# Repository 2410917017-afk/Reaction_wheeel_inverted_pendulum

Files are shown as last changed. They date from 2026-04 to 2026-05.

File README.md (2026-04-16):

# Reaction Wheel Inverted Pendulum 

> Plataforma educativa open-source de control moderno basada en un péndulo invertido con rueda de inercia. Implementa control LQR (Regulador Cuadrático Lineal) con modelado por mecánica Lagrangiana, simulación en MATLAB y hardware basado en ESP32.

<p align="center">
  Ensamble CAD
</p>

<p align="center">
  
  
  
  
  
</p>

---

##  Descripción del proyecto

El **Reaction Wheel Inverted Pendulum (RWIP)** es un sistema mecatrónico que mantiene un péndulo en posición vertical utilizando el momento angular generado por una rueda giratoria montada en su extremo superior. A diferencia del péndulo de carro clásico, no requiere traslación lineal — el único actuador es el motor que acelera y desacelera la rueda de inercia.

Este proyecto implementa:

- **Modelado matemático completo** mediante mecánica Lagrangiana
- **Linealización** del sistema no lineal alrededor del punto de equilibrio inestable
- **Representación en espacio de estados** con verificación de controlabilidad
- **Diseño del controlador LQR** mediante la ecuación algebraica de Riccati
- **Simulación no lineal** en MATLAB/Simulink con comparación lineal vs no lineal
- **Sensado** con encoder incremental óptico (ángulo péndulo) y encoder magnético AS5600 (velocidad rueda)
- **Estructura mecánica** completamente imprimible en 3D

---

##  Motivación y problemática

Los estudiantes de ingeniería en control moderno aprenden conceptos como espacio de estados y LQR sin acceso a plantas físicas para experimentar. Las plataformas comerciales equivalentes como el **Quanser QUBE-Servo 2** tienen un costo de entre **\$3,000 y \$8,000 USD**, lo que las hace inaccesibles para la mayoría de instituciones educativas en México y Latinoamérica.

Este proyecto propone una plataforma educativa **open-source y replicable** con un costo de aproximadamente **\$30–45 USD**, que permite:

- Derivar y verificar experimentalmente el modelo matemático de un sistema no lineal real
- Implementar y comparar estrategias de control (PID vs LQR)
- Visualizar en tiempo real el efecto de cada ganancia del controlador
- Replicarse en cualquier institución con impresora 3D

El principio físico de las reaction wheels es el mismo utilizado en **satélites y telescopios espaciales** para control de actitud sin propulsión química, lo que le da al proyecto un contexto de aplicación de alto impacto.

---

##  Teoría y fundamentos

### Sistema físico

El sistema tiene **2 grados de libertad**:
- `θ` — ángulo del péndulo respecto a la vertical
- `φ` — ángulo de la rueda respecto al péndulo

### Ecuaciones de movimiento (Lagrangiano)

La energía cinética total del sistema es:

$$T = \frac{1}{2}(I_p + m_w L^2)\dot{\theta}^2 + \frac{1}{2}I_w(\dot{\theta} + \dot{\phi})^2$$

Donde el primer término incluye la contribución traslacional de la rueda mediante el teorema de Steiner. Aplicando las ecuaciones de Euler-Lagrange se obtiene:

$$\ddot{\theta} = \frac{(m_p l + m_w L)g\sin\theta - \tau}{I_{total}}$$

$$\ddot{\phi} = \frac{\tau}{I_w} - \ddot{\theta}$$

### Linealización y espacio de estados

Linealizando alrededor de `θ = 0` con `sin θ ≈ θ`, el sistema toma la forma:

$$\dot{\mathbf{x}} = A\mathbf{x} + Bu, \quad \mathbf{x} = \begin{bmatrix}\theta \\ \dot{\theta} \\ \dot{\phi}\end{bmatrix}$$

$$A = \begin{bmatrix} 0 & 1 & 0 \\ \frac{M_g}{I_{total}} & 0 & 0 \\ -\frac{M_g}{I_{total}} & 0 & -\frac{b_{eq}}{I_w} \end{bmatrix}, \quad B = \begin{bmatrix} 0 \\ -\frac{1}{I_{total}} \\ \frac{1}{I_w} + \frac{1}{I_{total}} \end{bmatrix}$$

### Control LQR

El controlador LQR minimiza la función de costo:

$$J = \int_0^\infty (\mathbf{x}^T Q \mathbf{x} + u^T R u)\, dt$$

Las ganancias óptimas `K` se obtienen resolviendo la Ecuación Algebraica de Riccati:

$$A^T P + PA - PBR^{-1}B^T P + Q = 0 \quad \Rightarrow \quad K = R^{-1}B^T P$$

La ley de control es `u = -Kx`, con `u` siendo el voltaje aplicado al motor.

Para la derivación completa con todos los pasos intermedios, ver [`docs/teoria_completa.pdf`](docs/teoria_completa.pdf).

---

##  Estructura del repositorio

```
Reaction_wheel_pendulum/
│
│
├── CAD/                             # Diseño mecánico
│   ├── STL/                         # Archivos listos para imprimir
│   │   ├── Arm_V10_STL.stl
│   │   ├── Support_V5.stl
│   │   ├── Tower_V7_STL.stl
│   │   └── Wheel_V5_STL.stl
│   ├──planos/                      # Planos dimensionales PDF
│   │   ├── Arm.pdf
│   │   ├── ExplodedView.pdf
│   │   ├── Support_V5.pdf
│   │   ├── Tower_V7.pdf
│   │   └── Wheel_V5_Sheet.pdf
│   └──step/                        # Archivos STEP 
│       └── ensamble_completo.step
│
├── System_dinamics_test/            # Simulación y diseño de control
│   ├── params.m                     # Parámetros físicos del sistema
│   ├── model.m                      # Matrices A,B, controlabilidad, LQR
│   ├── simulation.m                 # Simulación no lineal ODE45
│   ├── system.m                     # Función dinámica no lineal 
│   └── resultados/                  # Gráficas exportadas
│       ├── respuesta_lineal.png
│       ├── simulacion_no_lineal.png
│       ├── lineal_vs_nolineal.png
│       └── lugar_de_raices.png
│
├── docs/                            # Documentación adicional
│   ├── teoria_completa.pdf          # Derivación matemática completa
│   └── img/
│       └── Assembly 1.png
│
├── src/                        # Código ESP32
│   ├── main/
│   │   ├── rwp_main.ino             # Controlador LQR completo
│   │   └── real_time_monitor.py     # Monitor en tiempo real
│   └── tools/
│       ├── sensors.h                # Lectura AS5600 + Encoder
│       └── identify_deadzone.ino    # Identificación zona muerta motor
│
├── electronics/                     # Diseño electrónico
│   └── schematic.pdf                # Esquemático completo
│
├── README.md
└── LICENSE

```

---

##  Hardware requerido

### Lista de componentes

| Componente | Modelo | Cantidad | Función | Costo aprox. |
|---|---|---|---|---|
| Microcontrolador | ESP32 DevKit v1 | 1 | Control en tiempo real | \$5–8 USD |
| Encoder ángulo péndulo | 3806-OPTI-600-AB-OC | 1 | Medir θ | (disponible) |
| Encoder velocidad rueda | AS5600 + imán diametral | 1 | Medir φ̇ | \$3–4 USD |
| Motor reaction wheel | Motor DC 775 sin reductora | 1 | Actuador | \$5–8 USD |
| Driver de motor | L298N o TB6612FNG | 1 | Amplificar señal PWM | \$2–4 USD |
| Fuente de poder | LiPo 18V o fuente regulada | 1 | Alimentación motor | \$8–12 USD |
| Rodamientos | 608-2RS (8mm) | 2 | Pivote del péndulo | \$1–2 USD |
| Tornillería | M3 × 10mm, M3 × 20mm | surtido | Ensamble | \$1 USD |
| Filamento 3D | PLA o PETG | ~250g | Estructura | \$3–5 USD |

**Costo total estimado: \$28–44 USD**

### Parámetros físicos del sistema (CAD)

| Parámetro | Símbolo | Valor | Fuente |
|---|---|---|---|
| Masa brazo + motor | `m_p` | 0.42 kg | Onshape |
| Distancia pivote-CM péndulo | `l` | 0.18 m | Onshape |
| Distancia pivote-rueda | `L` | 0.20 m | Onshape |
| Inercia total respecto al pivote | `I_total` | 0.0212 kg·m² | Onshape |
| Masa de la rueda | `m_w` | 0.09 kg | Onshape |
| Radio de la rueda | `r_w` | 0.06 m | CAD |
| Inercia de la rueda | `I_w` | 3.24×10⁻⁴ kg·m² | Calculado |

### Parámetros del motor 775

| Parámetro | Símbolo | Valor | Fuente |
|---|---|---|---|
| Resistencia de armadura | `Ra` | 0.80 Ω | Datasheet / medición |
| Constante de torque | `Kt` | 0.038 N·m/A | Datasheet / medición |
| Constante FCEM | `Ke` | 0.038 V·s/rad | Datasheet / medición |
| Voltaje nominal | `Vmax` | 18 V | — |
| Torque máximo | `τ_max` | 0.855 N·m | Calculado |

---

Notas:
  • Encoder 3806: pull-up 3.3kΩ en canal A y B hacia 3.3V (open collector)
  • AS5600: imán diametral centrado a 0.5–3mm del sensor
  • Capacitor 100µF entre VCC y GND del driver (desacoplo)
  • Masa común entre ESP32, driver y fuente

El esquemático completo en EasyEDA se encuentra en [`electronics/schematic.pdf`](electronics/schematic.pdf).

---

##  Instalación y uso

### Requisitos

- Arduino IDE 2.x con soporte ESP32 (board manager: `https://dl.espressif.com/dl/package_esp32_index.json`)
- Librería `Wire.h` (incluida en ESP32 core)
- MATLAB R2022a o superior (para simulación)
- Python 3.8+ con `pyserial` y `matplotlib` (para telemetría en tiempo real)

### 1. Clonar el repositorio

```bash
git clone https://github.com/tu-usuario/reaction-wheel-pendulum.git
cd reaction-wheel-pendulum
``` 

### 2. Configurar parámetros

Edita `firmware/main/config.h` con tus ganancias de MATLAB:

```cpp
// Ganancias LQR — copiar exactamente de MATLAB
const float K_theta    = 15.0;
const float K_thetadot = 8.0;
const float K_phidot   = 2.0;

// Parámetros del sistema
const float VMAX          = 18.0;
const float THETA_MAX_DEG = 25.0;
const int   PWM_DEADZONE  = 18;
```

### 3. Cargar firmware al ESP32

```bash
# Desde Arduino IDE: seleccionar placa "ESP32 Dev Module"
# Puerto: el que corresponda a tu ESP32
# Cargar rwp_main.ino
```

### 4. Flujo de operación

```
1. Encender → verificar salida serial (115200 baud)
2. Confirmar "✓ Imán OK" del AS5600
3. Posicionar péndulo en vertical
4. Enviar cualquier carácter por serial → establece cero
5. Enviar 'S' → activa el controlador
6. Enviar 'P' → pausa
7. Enviar 'R' → restablece cero si el péndulo cayó
```

### 5. Visualización en tiempo real (opcional)

```bash
pip install pyserial matplotlib
python docs/graficar_serial.py
# Editar PORT en el script según tu sistema
```

---

##  Simulación en MATLAB

### Correr la simulación completa

```matlab
% En MATLAB, desde la carpeta /matlab:
run('Parametros.m')   % 1. Cargar parámetros físicos
run('Modelo.m')       % 2. Diseñar LQR y verificar estabilidad
run('Simulacion.m')   % 3. Simular sistema no lineal
```

### Parámetros de diseño LQR

```matlab
% Matrices de peso — ajustables
Q = diag([10, 8, 5]);   % [q_theta, q_thetadot, q_phidot]
R = 300;                % penalización del esfuerzo de control
```

### Resultados de simulación

| Métrica | Valor |
|---|---|
| Condición inicial | 8.59° |
| Tiempo de establecimiento | 0.140 s |
| Sobreimpulso | 0.0 % |
| Control máximo | 4.59 V |
| Margen de voltaje | 74.5% |
| Polos en lazo cerrado | parte real negativa ✓ |

---

##  Resultados

### Respuesta del controlador LQR

<p align="center">
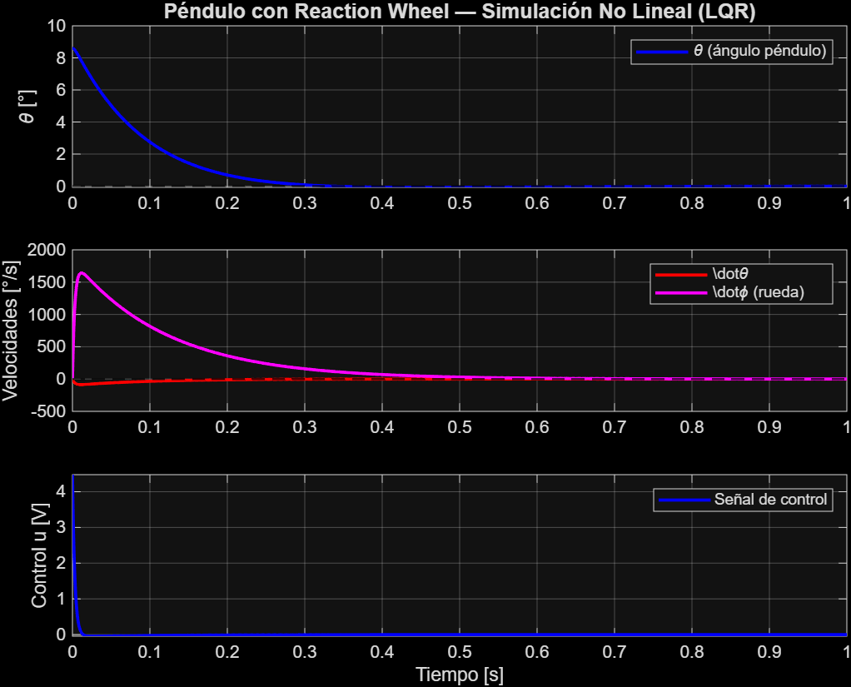
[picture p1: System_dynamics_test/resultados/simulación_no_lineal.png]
  
</p>

### Comparación modelo lineal vs no lineal

<p align="center">
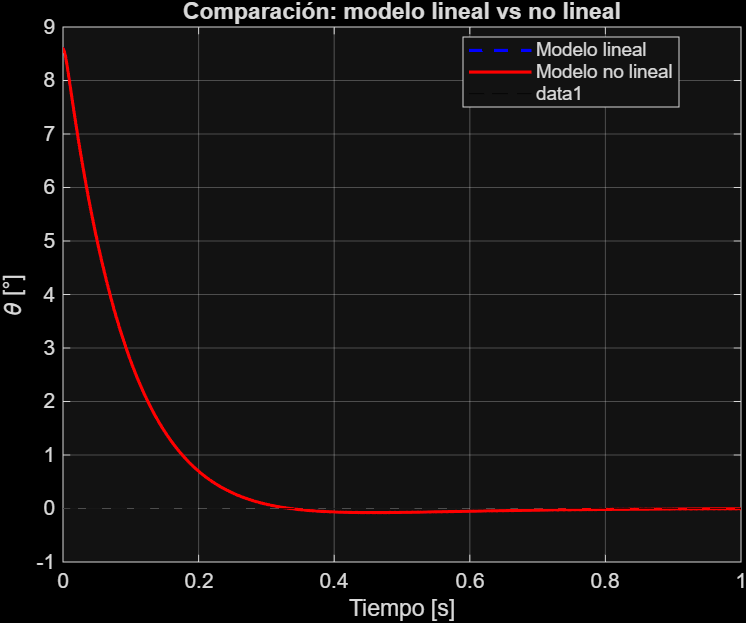
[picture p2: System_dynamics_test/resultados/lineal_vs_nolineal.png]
  
</p>

La diferencia entre ambos modelos corresponde al error de linealización (`sinθ ≈ θ`), que produce un undershoot de ~0.8° en el modelo no lineal. Este comportamiento es esperado y se documenta como parte del análisis de validez del modelo linealizado.

---

##  Trabajo futuro

- [ ] **Identificación experimental** de parámetros del motor (Kt, Ra, Ke)
- [ ] **Comparación PID vs LQR** con métricas cuantitativas (ISE, IAE, ITAE)
- [ ] **Control swing-up** mediante control por energía para llevar el péndulo desde posición colgante hasta vertical
- [ ] **Filtro de Kalman** para estimación de estados con fusión de sensores
- [ ] **Extensión a 2 ejes** (dual axis reaction wheel — balanceo sobre una punta)
- [ ] **Interfaz web** vía WiFi del ESP32 para ajuste de ganancias en tiempo real
- [ ] **Validación experimental** con comparación cuantitativa simulación vs hardware

---

##  Referencias

1. Krafes, S. et al. *"Design, Implementation, and Control of a Wheel-Based Inverted Pendulum"*, MDPI Electronics, 2024. [DOI: 10.3390/electronics13030514](https://doi.org/10.3390/electronics13030514)

2. Nguyen, B.H. et al. *"Modelling and control of a reaction wheel pendulum using a linear quadratic regulator"*, ResearchGate, 2021. [Link](https://www.researchgate.net/publication/351314795)

3. Gajamohan, M. et al. *"Nonlinear Analysis and Control of a Reaction Wheel-based 3D Inverted Pendulum (Cubli)"*, ETH Zürich, 2013. [PDF](https://ethz.ch/content/dam/ethz/special-interest/mavt/dynamic-systems-n-control/idsc-dam/Research_DAndrea/Cubli/RevisedManuscript.pdf)

4. Borase, R.P. et al. *"Reaction Wheel Pendulum Stabilization Using Various State-Space Representations"*, MDPI Electronics, 2025. [DOI: 10.3390/electronics14234719](https://doi.org/10.3390/electronics14234719)

5. SimpleFOC Project. *"Arduino BLDC Reaction Wheel Inverted Pendulum"*. [GitHub](https://github.com/simplefoc/Arduino-FOC-reaction-wheel-inverted-pendulum)

6. Rouleau, M. *"Self-Balancing Stick — Dual Axis Reaction Wheel Inverted Pendulum"*. [GrabCAD](https://grabcad.com/library/self-balancing-stick-dual-axis-reaction-wheel-inverted-pendulum-1)

---

##  Autor

Desarrollado como **proyecto integrador de 5° cuatrimestre** de la carrera de Ingeniería Mecatrónica **Institución:** Universidad Tecnológica de Corregidora
**Materia:** Sistemas de Control / Proyecto Integrador  
**Periodo:** 2026

---

##  Licencia

Este proyecto está bajo la licencia MIT. Consulta el archivo [LICENSE](LICENSE) para más detalles.

Puedes usar, modificar y distribuir este proyecto libremente, incluyendo para fines educativos e institucionales. Si lo usas en un trabajo académico, se agradece la cita correspondiente.

---

<p align="center">
  Hecho con café y demasiadas horas en MATLAB
</p>

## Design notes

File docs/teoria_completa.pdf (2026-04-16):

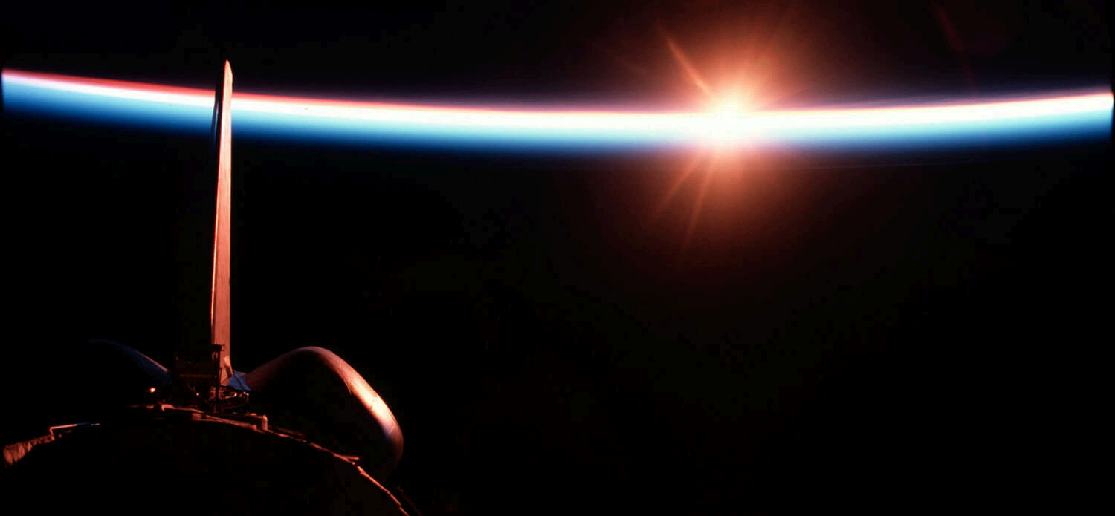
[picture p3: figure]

# Teoría sobre: Péndulo invertido con rueda de reacción

## Definición del sistema

Primero establece claramente qué es el sistema físicamente antes de escribir una sola ecuación.

### Variables y parámetros

Parámetros físicos:
m_p = masa del cuerpo del péndulo (brazo + motor) m_w = masa de la reaction wheel
l | = distancia del pivote al CM del péndulo
L | = longitud total del brazo
I_p = momento de inercia del péndulo respecto al pivote I_w = momento de inercia de la rueda respecto a su centro
g | = 9.81 m/s²
τ | = torque del motor (entrada de control)

Coordenadas generalizadas:
θ | = ángulo del péndulo respecto a la vertical (= 0 arriba)
φ | = ángulo de la rueda respecto al péndulo

El sistema tiene 2 grados de libertad, 2 coordenadas generalizadas y terminan en 2 ecuaciones de movimiento.

## Parte 2 — Formalismo de Euler-Lagrange

Con Newton necesitas calcular fuerzas de reacción internas. Con Lagrange trabajas directamente con energías, que son escalares y mucho más fáciles de manejar. La

Teoría sobre: Péndulo invertido con rueda de reacción | 1

ecuación fundamental es:

Donde:

L = T - V es el Lagrangiano

q_i son las coordenadas generalizadas

Q_i son las fuerzas o torques externos

## Parte 3 — Energía cinética

El sistema tiene dos cuerpos en movimiento: el péndulo y la rueda.

### Energía cinética del péndulo

El péndulo rota alrededor del pivote fijo con velocidad angular θ̇ :

### Energía cinética de la rueda

La rueda tiene dos movimientos simultáneos:

Rota con el péndulo a velocidad θ̇

Rota respecto al péndulo a velocidad φ̇

Su velocidad angular absoluta es la suma:

### Energía cinética total

Expandiendo el cuadrado:

## Parte 4 — Energía potencial

Solo la gravedad contribuye. Tomando como referencia el nivel del pivote, el CM del péndulo sube o baja según θ :

−
dt

d (
∂q˙i

∂L ) =
∂qi

∂L Qi

Tp = I
2

1
pθ

˙2

## Tw = I ( +

2

1
w θ

˙ ϕ)

˙ 2

T = Tp + Tw = I +
2

1
pθ

˙2 I ( +
2

1
w θ

˙ ϕ)

˙ 2

## T = (I + I ) + I + I

2

1
p | w θ
˙2 | wθ

˙ϕ˙
2

1
wϕ˙2

La rueda está al final del brazo a distancia L , y su CM coincide con el eje del motor. Simplificando con M = m_p referido al CM y agrupando:

Una convención común al formular esta ecuación es tomarlo como positivo, esto debido el eje cartesiano con el que se referencia el ángulo θ :

## Parte 5 — El Lagrangiano

## Parte 6 — Aplicar Euler-Lagrange

### Para θ

Paso 1 — Derivada parcial respecto a θ̇ :

Paso 2 — Derivada total respecto al tiempo:

Paso 3 — Derivada parcial respecto a θ :

Paso 4 — Ensamblar. El torque externo en θ es cero

V = −mpgl cos θ − mwgLcos θ

## V = −(mpl + mwL)g cos θ

V = (mpl + mwL)g cos θ

L = T − V

L = (I + I ) + I | + I | − (m l + m L)g cos θ
2

1
p | w θ
˙2 | wθ

˙ϕ˙
2

1
wϕ˙2
p | w

=
∂θ

˙

∂L

## (Ip + Iw)θ

## ˙ + Iwϕ˙

=
dt

d
∂θ

˙

∂L

## (Ip + Iw)θ¨+ Iwϕ¨

=
∂θ

∂L

## (mpl + mwL)g sin θ

Qθ = 0

−
dt

d
∂θ

˙

∂L =
∂θ

∂L
0

### Para φ

Paso 1 — Derivada parcial respecto a φ̇ :

Paso 2 — Derivada total respecto al tiempo:

Paso 3 — Derivada parcial respecto a φ :

Paso 4 — El torque externo en φ es el torque del motor τ :

## Parte 7 — Despejar las aceleraciones

De la ecuación (2):

Sustituyendo (2') en (1):

(Ip + Iw)θ + I | − (m l + m L)g sin θ = 0
¨ | wϕ¨
p | w | (1)

=
∂ϕ˙

∂L
Iwθ

## ˙ + Iwϕ˙ = Iw(θ

˙ + ϕ)

˙

=
dt

d
∂ϕ˙

∂L

## Iw(θ¨+ ϕ)¨

=
∂ϕ

∂L
0

Qϕ = τ

−
dt

d
∂ϕ˙

∂L =
∂ϕ

∂L
τ
Iw(θ + ) = τ ¨ ϕ¨ | (2)
ϕ¨ = | −
Iw

τ
θ¨ | (2’)
(Ip + Iw)θ¨+ Iw ( − | =
Iw τ | θ¨) (mpl + mwL)g sin θ

## (Ip + Iw)θ¨+ τ − Iwθ¨ = (mpl + mwL)g sin θ

Ipθ¨ = (mpl + mwL)g sin θ − τ

Y sustituyendo (3) en (2'):

Estas son las ecuaciones de movimiento no lineales del sistema. El sinθ es la no linealidad.

## Parte 8 — Linealización

El sistema opera cerca de θ = 0 (posición vertical). Para θ pequeño:

Definiendo por simplicidad:

Las ecuaciones linealizadas quedan:

## Parte 9 — Espacio de Estados

En lugar de manejar ecuaciones diferenciales de segundo orden, se define un vector de variables llamadas estados y reescribes todo como un sistema de ecuaciones de primer orden:

Donde A , B , C , D son matrices constantes, u es la entrada y y la salida.

### Definición de estados

Elige los estados como las variables que describen completamente el sistema en cualquier instante:

θ¨ =
Ip

## (mpl + mwL)g sin θ − τ

(3)

ϕ¨ = −
Iw

τ
Ip

## (mpl + mwL)g sin θ − τ

(4)

## sin θ ≈ θ, cos θ ≈ 1

Mg = (mpl + mwL)g

θ¨ =
Ip

Mg ⋅ θ − τ
(5)

ϕ¨ = −
Iw

τ
Ip

Mg ⋅ θ − τ
(6)

x˙ = Ax + Buy = Cx + Du

x = [x1 x2 x3] = [θ θ

˙ ϕ˙]

La entrada es el torque del motor:

### Derivadas de los estados

### Forma matricial

Los valores propios de A te dicen si el sistema es estable en lazo abierto. Si alguno tiene parte real positiva → inestable → necesitas control. Spoiler: sí los tiene, por eso el péndulo se cae solo.

### Verificar controlabilidad

Antes de diseñar el controlador verifica que el sistema sea controlable — que el actuador pueda afectar todos los estados:

Si det(C) ≠ 0 el sistema es controlable y puedes proceder.

## Parte 10 — Control LQR

### La idea central

LQR busca una ley de control de la forma:

Es decir, retroalimenta todos los estados con ganancias K_1, K_2, K_3 .

### La función de costo

LQR elige las ganancias que minimizan este índice de desempeño:

u = τ

x˙ 1 = θ

˙ = x2

## x˙ 2 = θ¨ = x −

Ip

Mg

### 1 u

Ip

1

## x˙ 3 = ϕ¨ = − x +

Ip

Mg

1 | ( + | u
Iw

1
Ip

1 )

C = [B AB A²B]

u = −Kx = − [K1 | K2 | K3] [θ θ

˙ ϕ

˙]

J = ∫ x Qx + u Ru dt

0

∞
(
T | T | )

El primer término penaliza que los estados se alejen del origen (que el péndulo se incline). El segundo penaliza el esfuerzo de control (que el motor trabaje de más). Tú decides qué tan importante es cada cosa eligiendo las matrices Q y R .

### Las matrices Q y R

Q es una matriz diagonal de 3×3 (uno por estado) y R es un escalar para este sistema:

Interpretación práctica:

q_1 grande → priorizas que θ vuelva a cero rápido → controlador agresivo en ángulo

q_2 grande → priorizas que θ̇ sea pequeña → penalizas oscilaciones

q_3 grande → priorizas que la rueda no acelere indefinidamente

r grande → el motor se mueve suavemente pero reacciona más lento

El tradeoff fundamental: entre más agresivo el control, más rápido estabiliza pero más corriente consume y más se desgasta el motor.

### La ecuación de Riccati

La solución matemática de ese problema de optimización lleva a resolver la Ecuación Algebraica de Riccati (ARE):

Esta ecuación tiene como incógnita la matriz P (simétrica positiva definida). Una vez resuelta, las ganancias óptimas son:

En la práctica no resuelves esto a mano — lo hace MATLAB con una línea:

% Datos del sistema
A = [...]; B = [...];
Q = diag([q1, q2, q3]);
R = r;

% Resolver Riccati y obtener ganancias [K, P, eig_cl] = lqr(A, B, Q, R);

% Verificar polos en lazo cerrado disp(eig_cl)

O en Python:

Q = [q1 | 0 0 0 q2 | 0 0 0 q3] , R = r

A P +

T PA − PBR B P +

−1 T Q = 0

K = R B P

−1 T

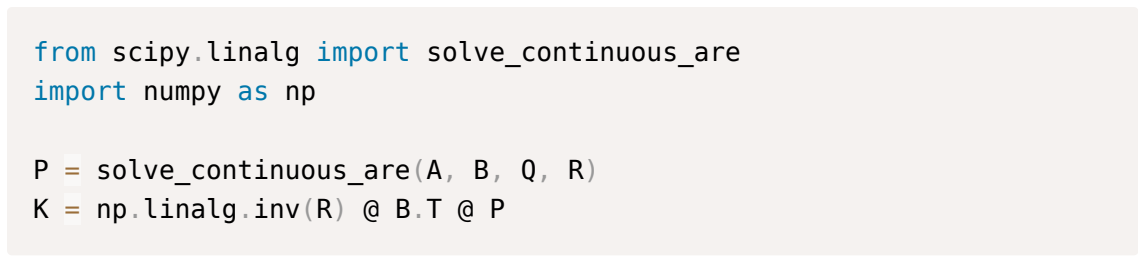
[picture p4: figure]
from scipy.linalg import solve_continuous_are import numpy as np; solve_continuous_are(A, B, Q, R); np.linalg.inv(R) @ B.T @ P

### Lazo cerrado

Sustituyendo u = -Kx en el sistema:

El sistema en lazo cerrado tiene matriz A_cl = A - BK . Los valores propios de esta matriz determinan la estabilidad — todos deben tener parte real negativa para que el péndulo se estabilice.

## Resumen del flujo completo

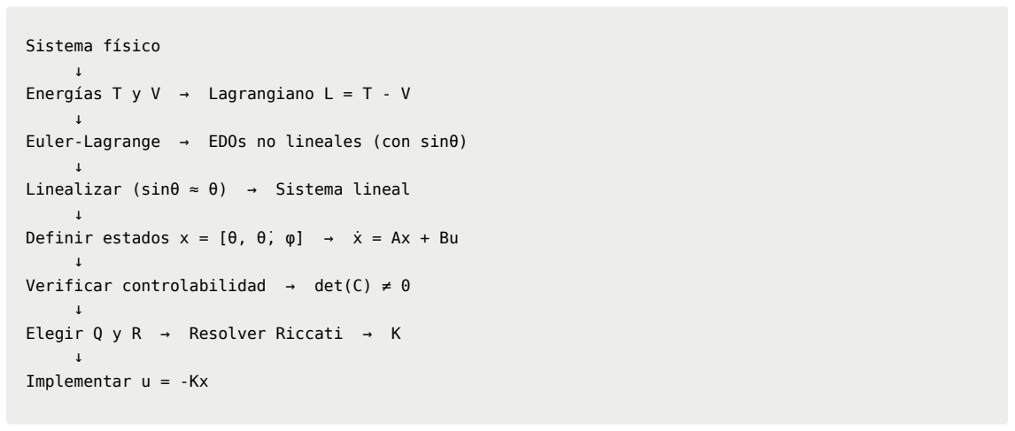
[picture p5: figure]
Sistema físico ↓ Energías T y V → Lagrangiano L = T - V ↓; ↓ Linealizar (sinθ ≈ θ) → Sistema lineal ↓; ↓ Verificar controlabilidad → det(C) ≠ 0 ↓ Elegir Q y R → Resolver Riccati → K ↓ Implementar u = -Kx

Euler-Lagrange → EDOs no lineales (con sinθ)

Definir estados x = [θ, θ̇, φ̇] → ẋ = Ax + Bu

## Referencias

1. Ogata, Katsuhiko. Ingeniería de control moderna. Quinta edición. México, D.F.: Prentice-Hall Hispanoamericana, 2017. (https://www.bing.com/ck/a?!&ptn=3&ver=2&hsh=4&fclid=2927917e-95d4-6cd1-2a0e-866794986d7e&ntb=1)
2. Krafes, S. et al. "Design, Implementation, and Control of a Wheel-Based Inverted Pendulum", MDPI Electronics, 2024. DOI: 10.3390/electronics13030514 (https://doi.org/10.3390/electronics13030514)
3. Nguyen, B.H. et al. "Modelling and control of a reaction wheel pendulum using a linear quadratic regulator", ResearchGate, 2021. Link (https://www.researchgate.net/publication/351314795)
4. Gajamohan, M. et al. "Nonlinear Analysis and Control of a Reaction Wheel-based 3D Inverted Pendulum (Cubli)", ETH Zürich, 2013. PDF (https://ethz.ch/content/dam/ethz/special-interest/mavt/dynamic-systems-n-control/idsc-dam/Research_DAndrea/Cubli/RevisedManuscript.pdf)

## x˙ = Ax + B(−Kx) = (A − BK)x

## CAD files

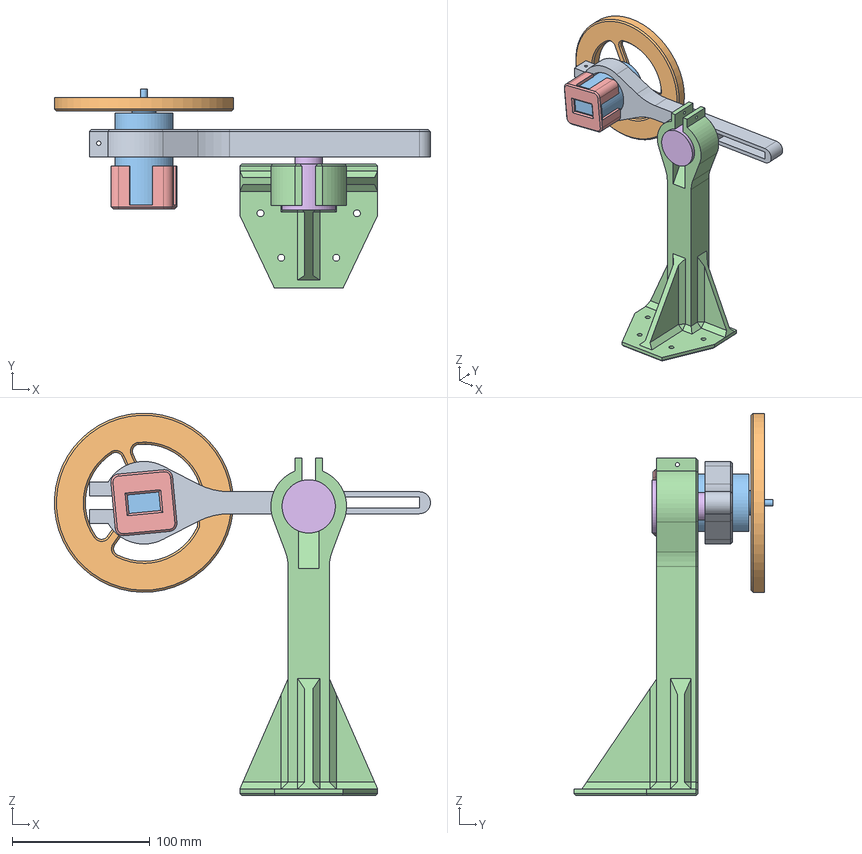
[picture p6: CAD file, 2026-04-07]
CAD/step/ensamble_completo.step
272.9 x 144.3 x 277.6 mm

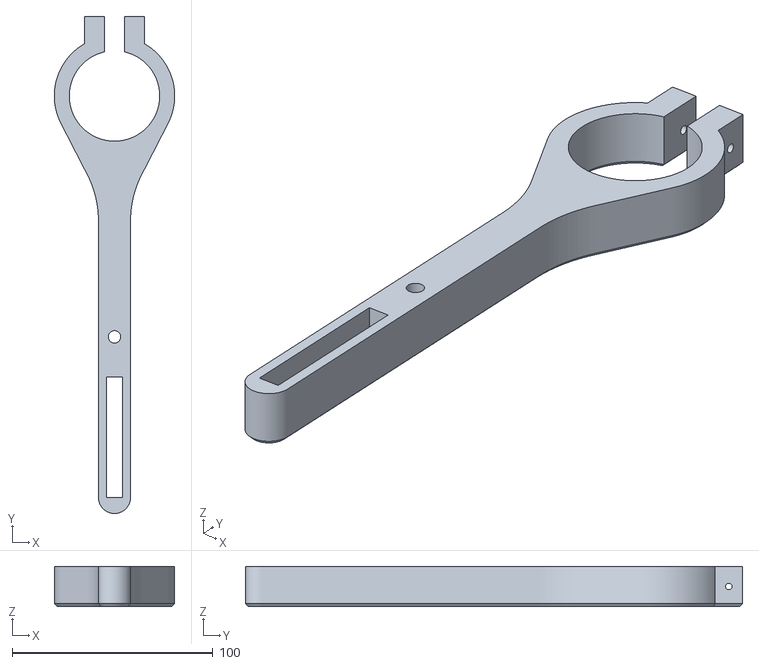
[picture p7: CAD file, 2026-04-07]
CAD/STL/Arm_V10_STL.stl
60.0 x 247.6 x 20.0

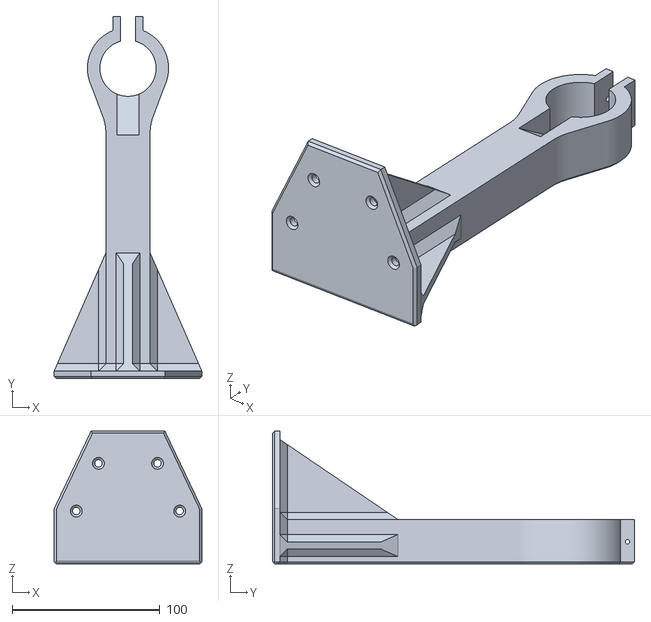
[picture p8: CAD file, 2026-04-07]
CAD/STL/Tower_V7_STL.stl
100.0 x 245.0 x 90.0

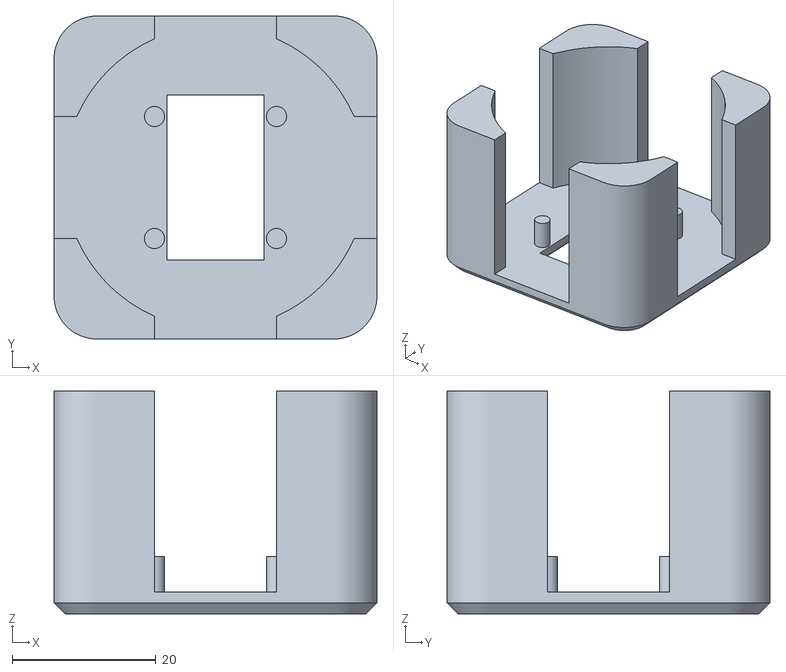
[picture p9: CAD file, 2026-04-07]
CAD/STL/Support_V5.stl
45.0 x 45.0 x 31.0

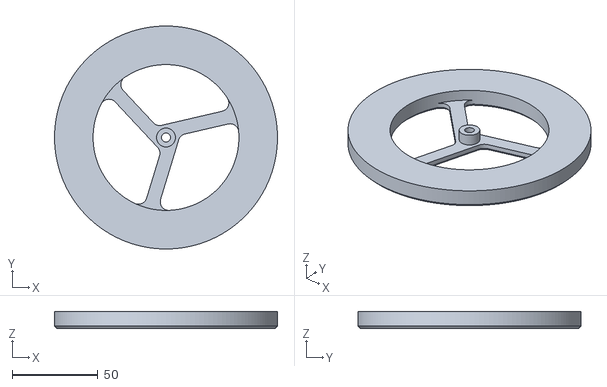
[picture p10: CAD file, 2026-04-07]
CAD/STL/Wheel_V5_STL.stl
130.0 x 130.0 x 10.0

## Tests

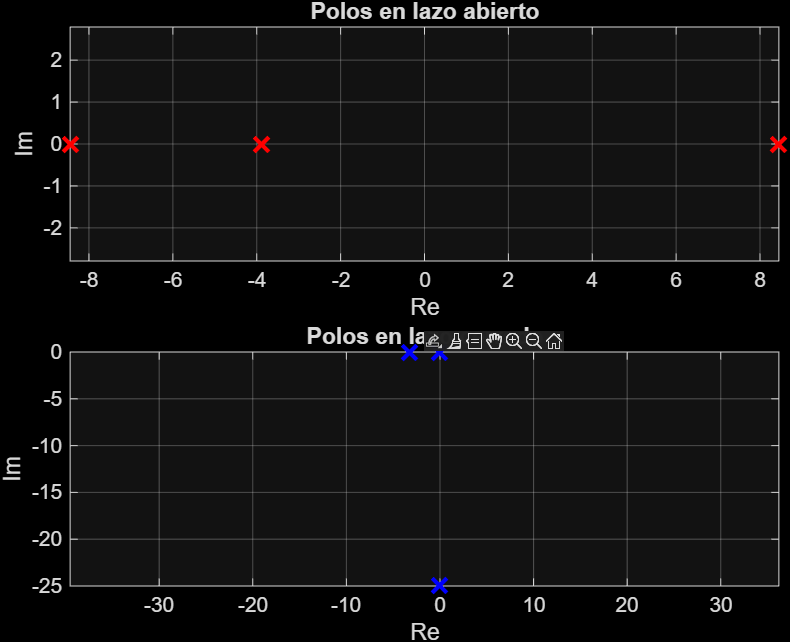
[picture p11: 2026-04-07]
System_dynamics_test/resultados/lugar_de_raices.png

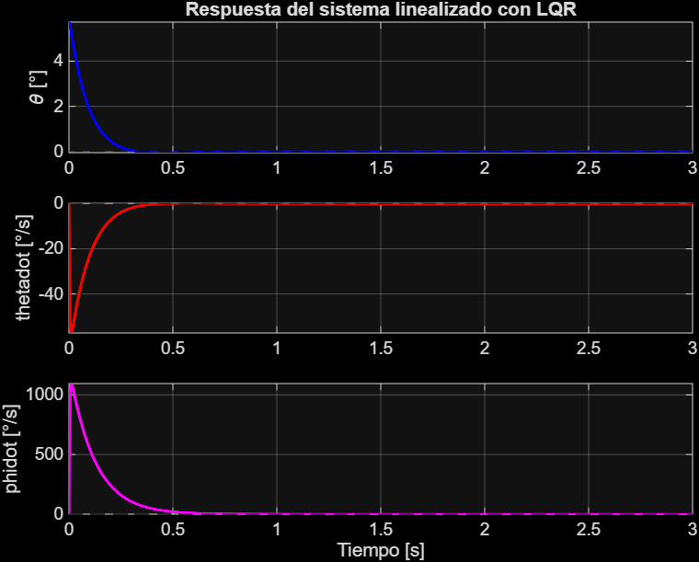
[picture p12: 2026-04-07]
System_dynamics_test/resultados/respuesta_lineal.png

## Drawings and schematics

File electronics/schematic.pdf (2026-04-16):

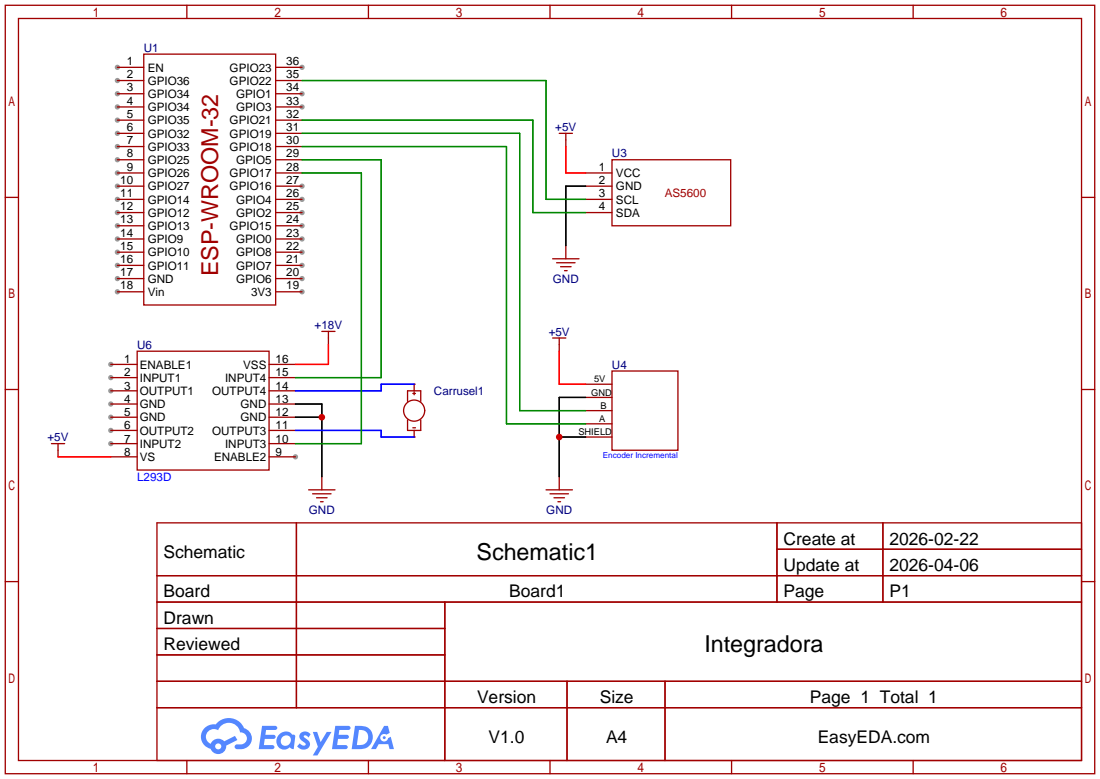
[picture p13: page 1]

Schematic | Schematic1 | Create at | 2026-02-22

Update at | 2026-04-06

Board | Board1 | Page | P1
Drawn | | Integradora
Reviewed

Version | Size | Page 1 Total 1
V1.0 | A4 | EasyEDA.com

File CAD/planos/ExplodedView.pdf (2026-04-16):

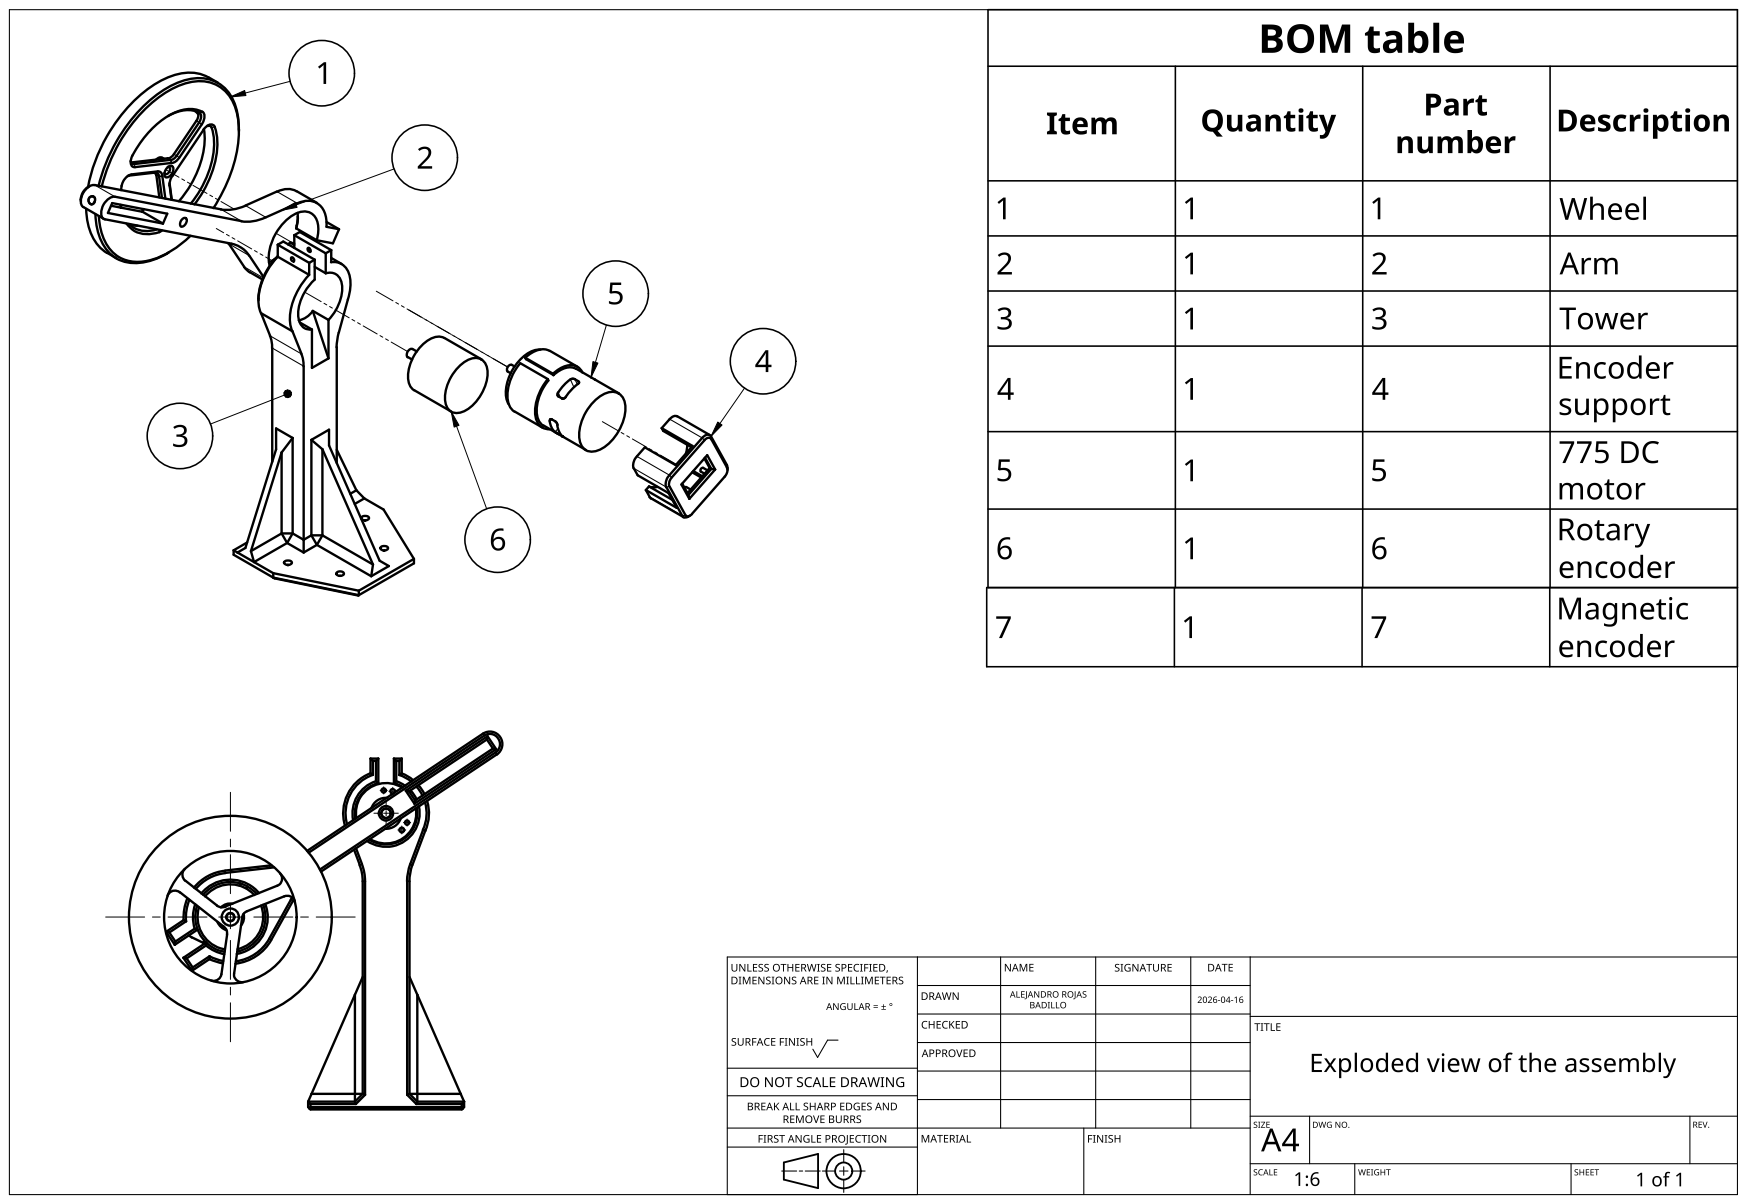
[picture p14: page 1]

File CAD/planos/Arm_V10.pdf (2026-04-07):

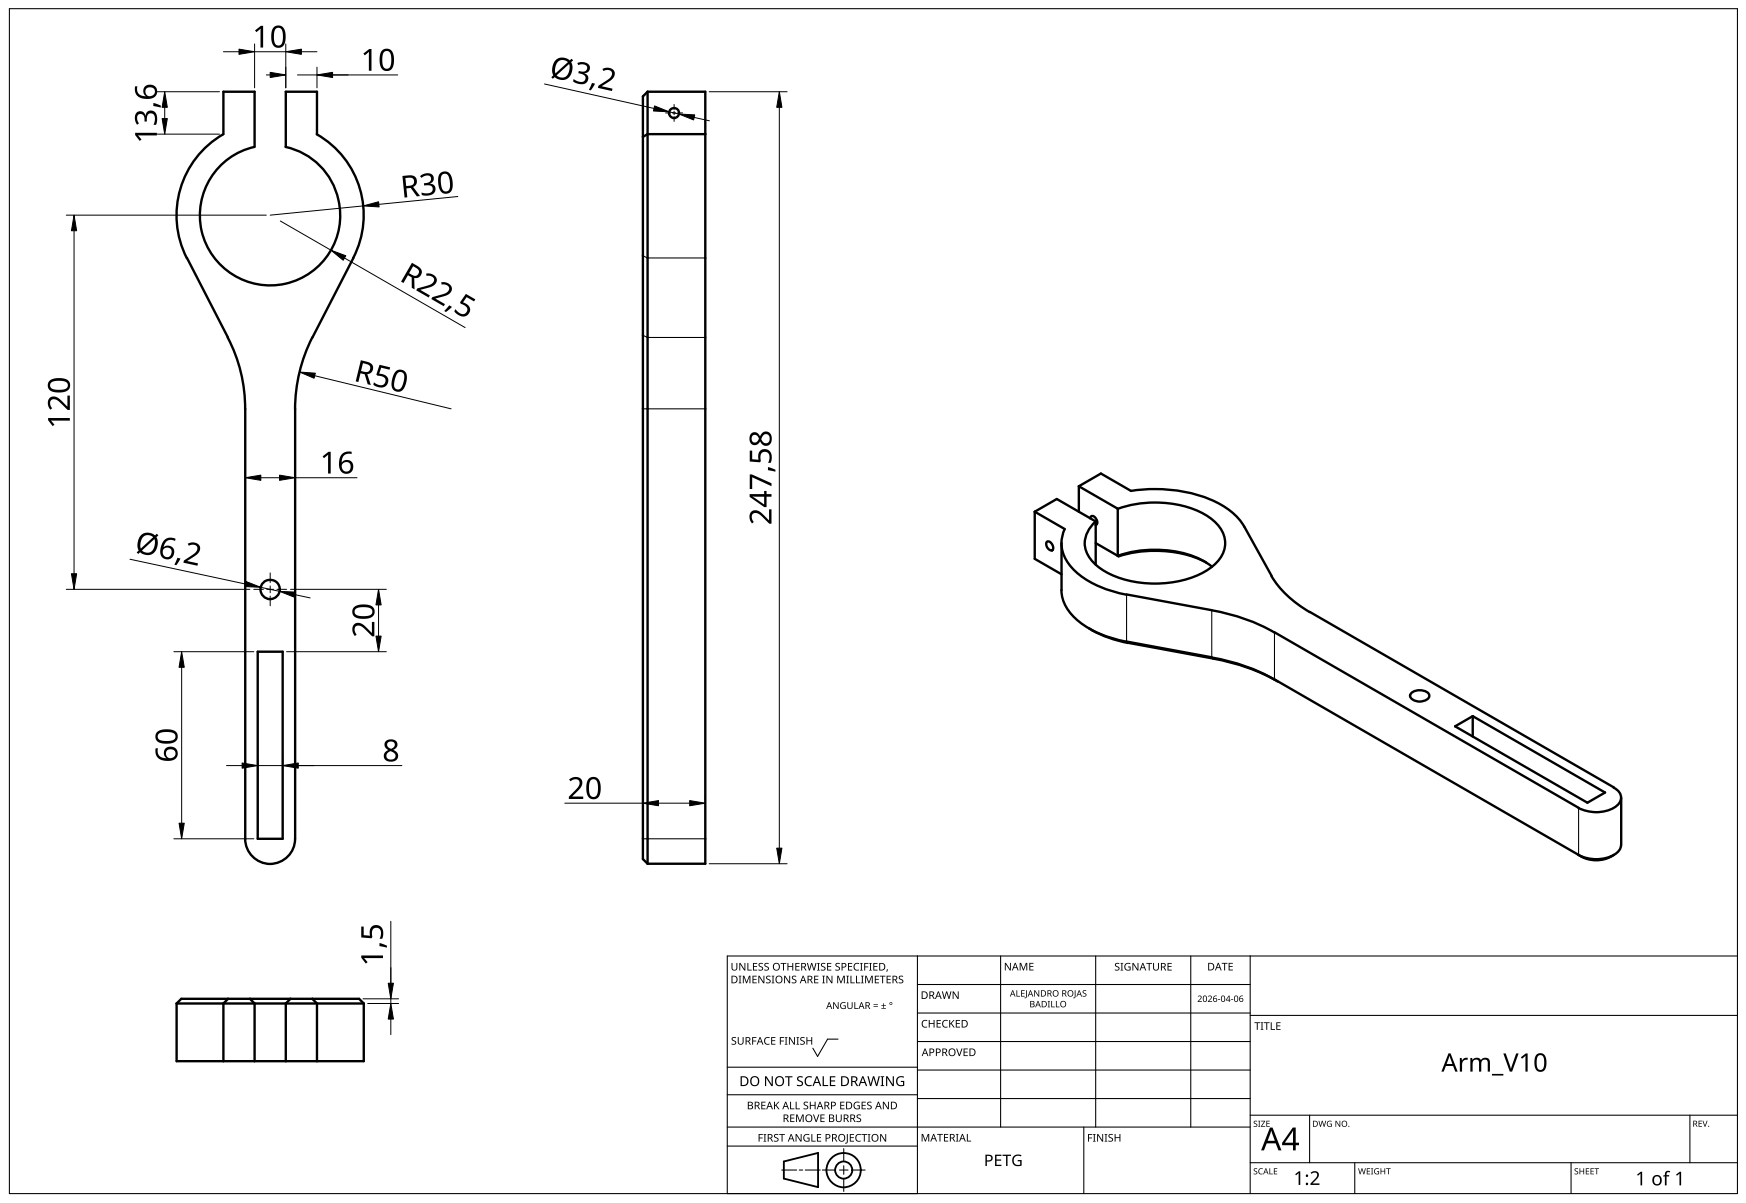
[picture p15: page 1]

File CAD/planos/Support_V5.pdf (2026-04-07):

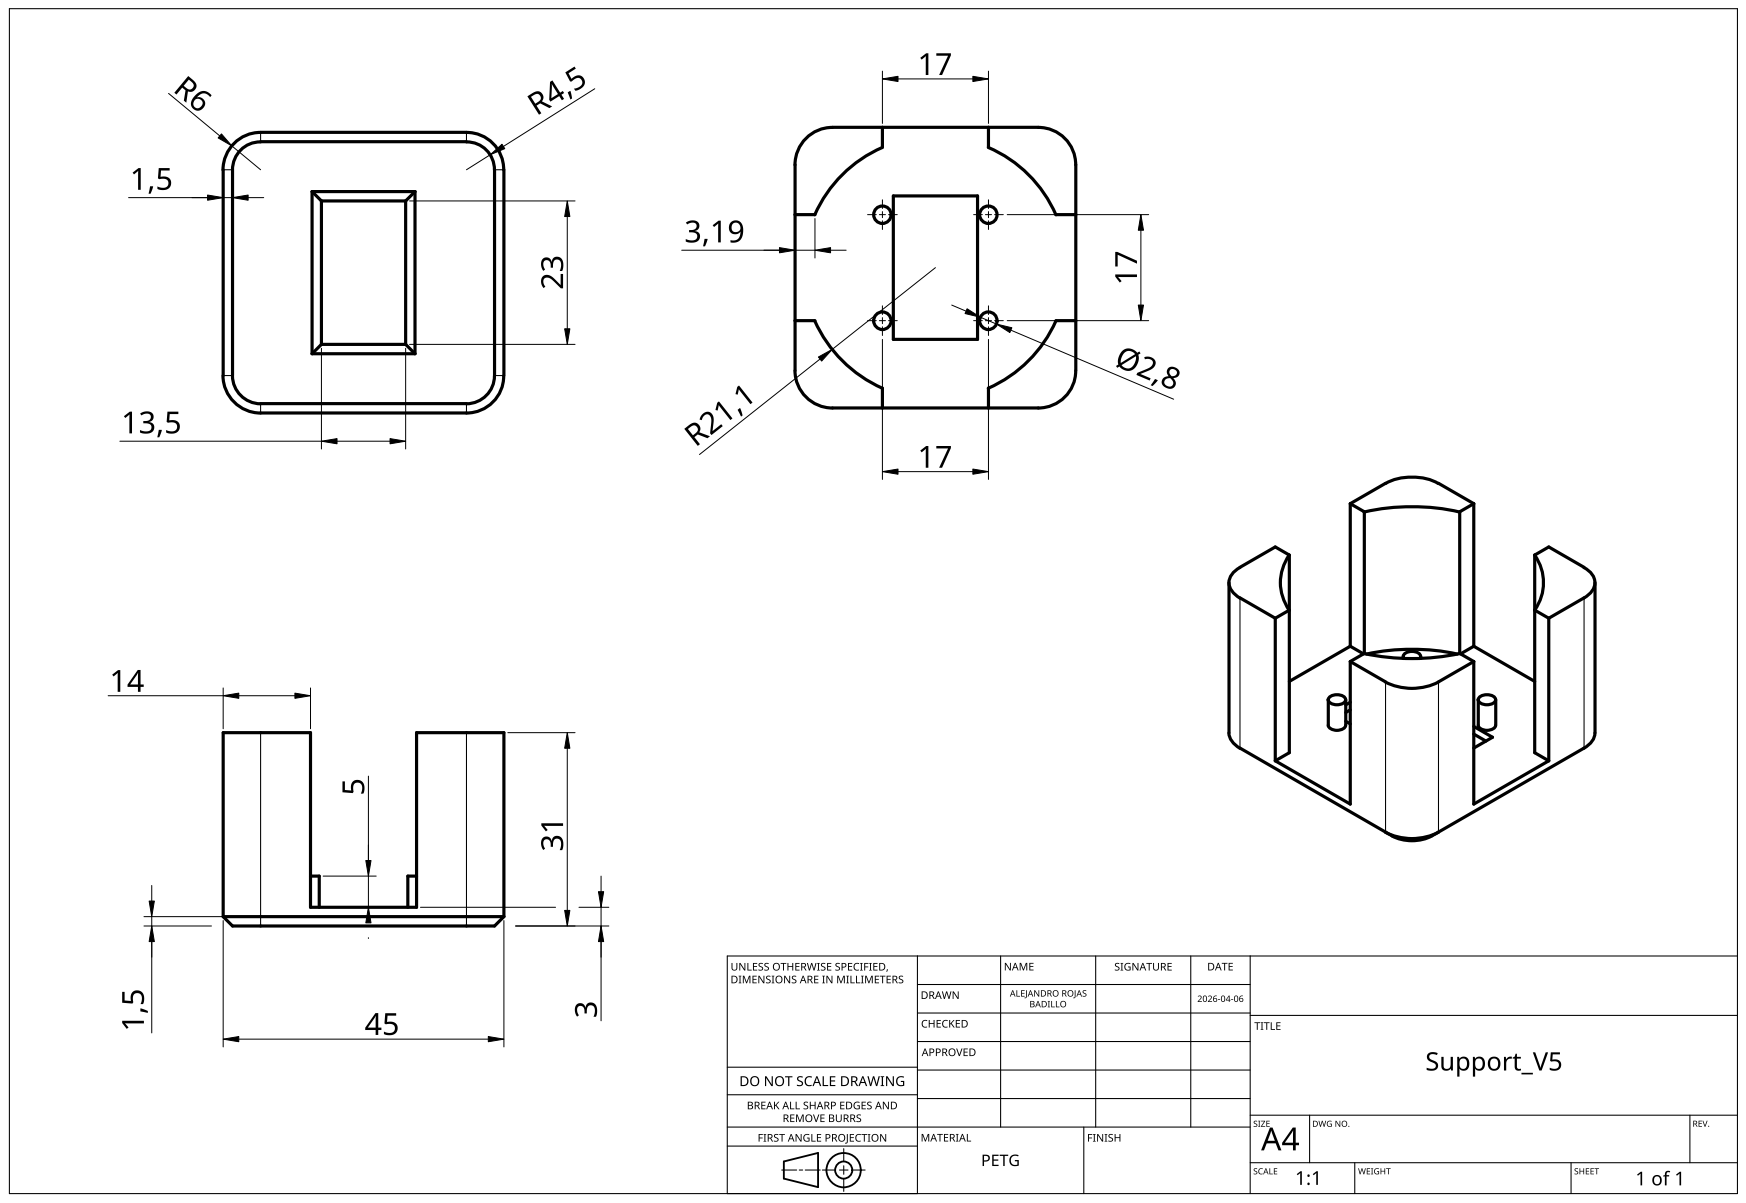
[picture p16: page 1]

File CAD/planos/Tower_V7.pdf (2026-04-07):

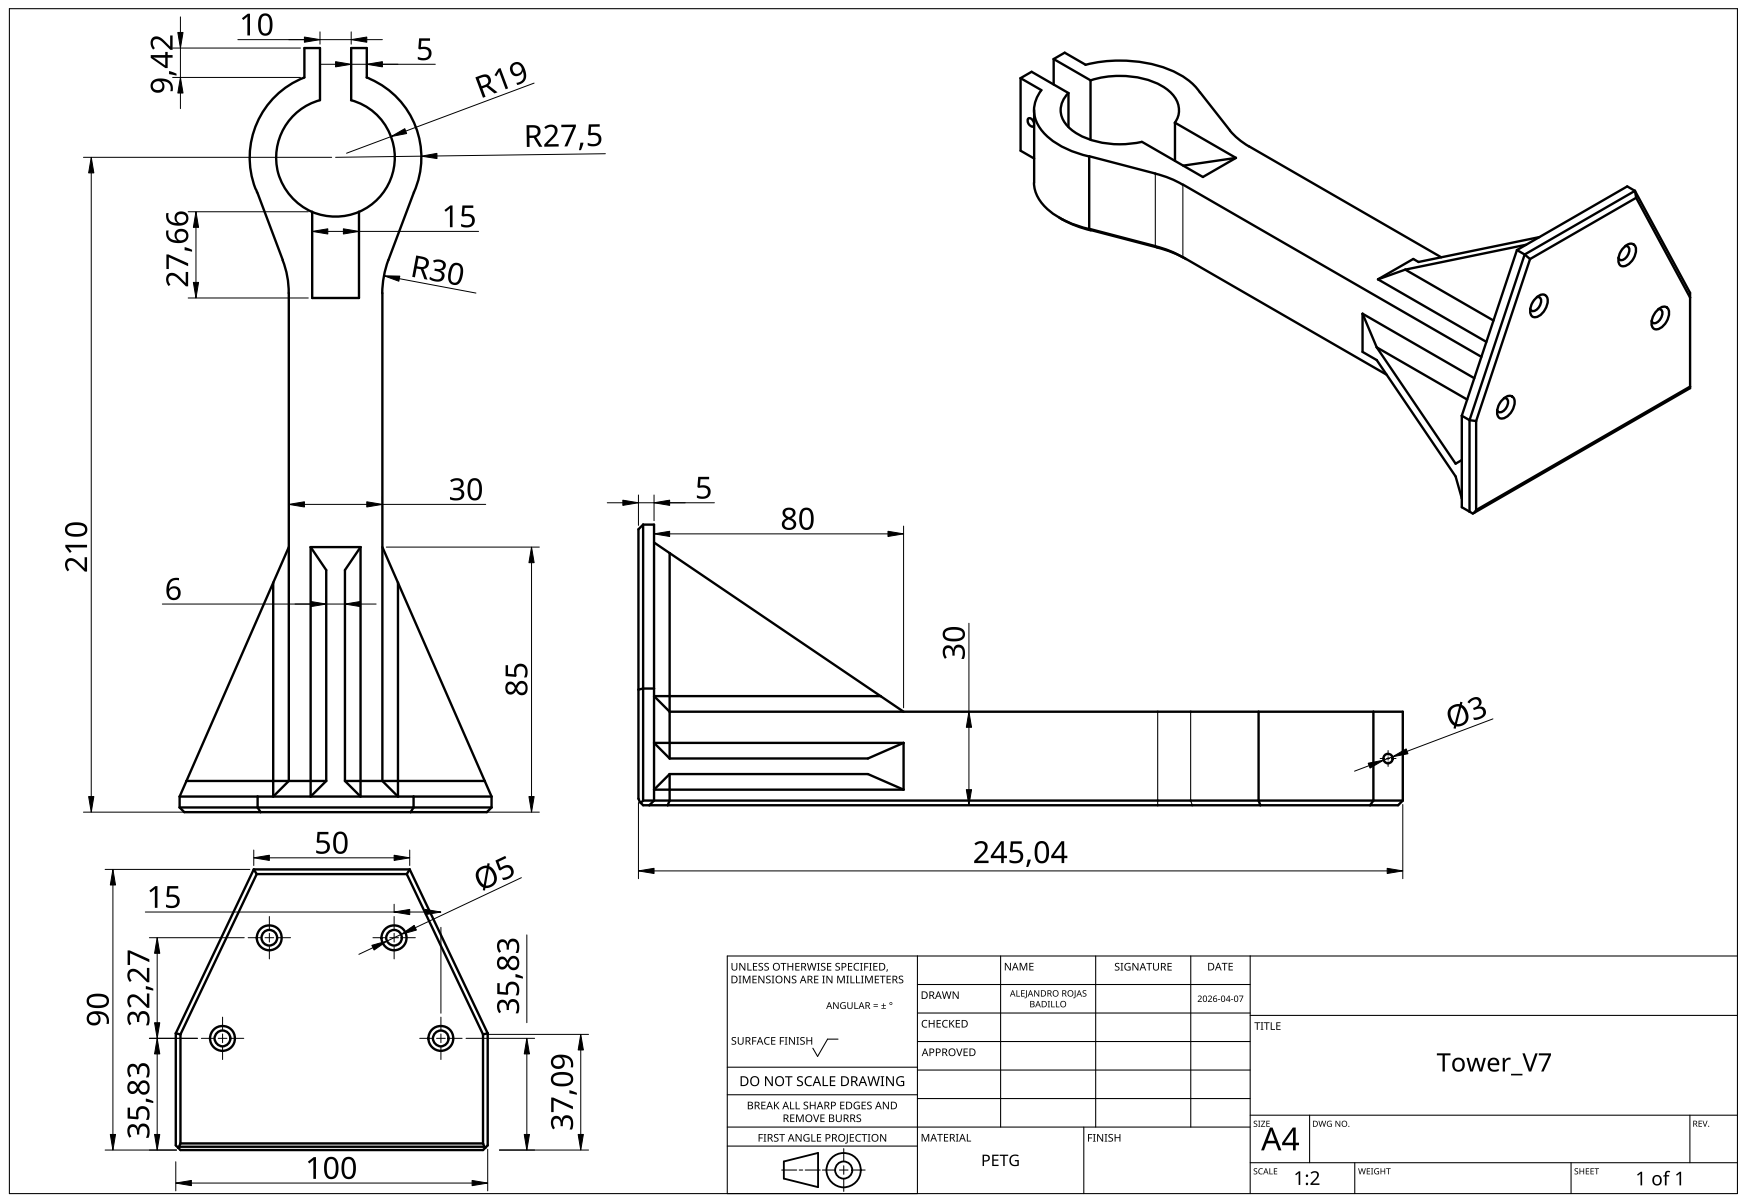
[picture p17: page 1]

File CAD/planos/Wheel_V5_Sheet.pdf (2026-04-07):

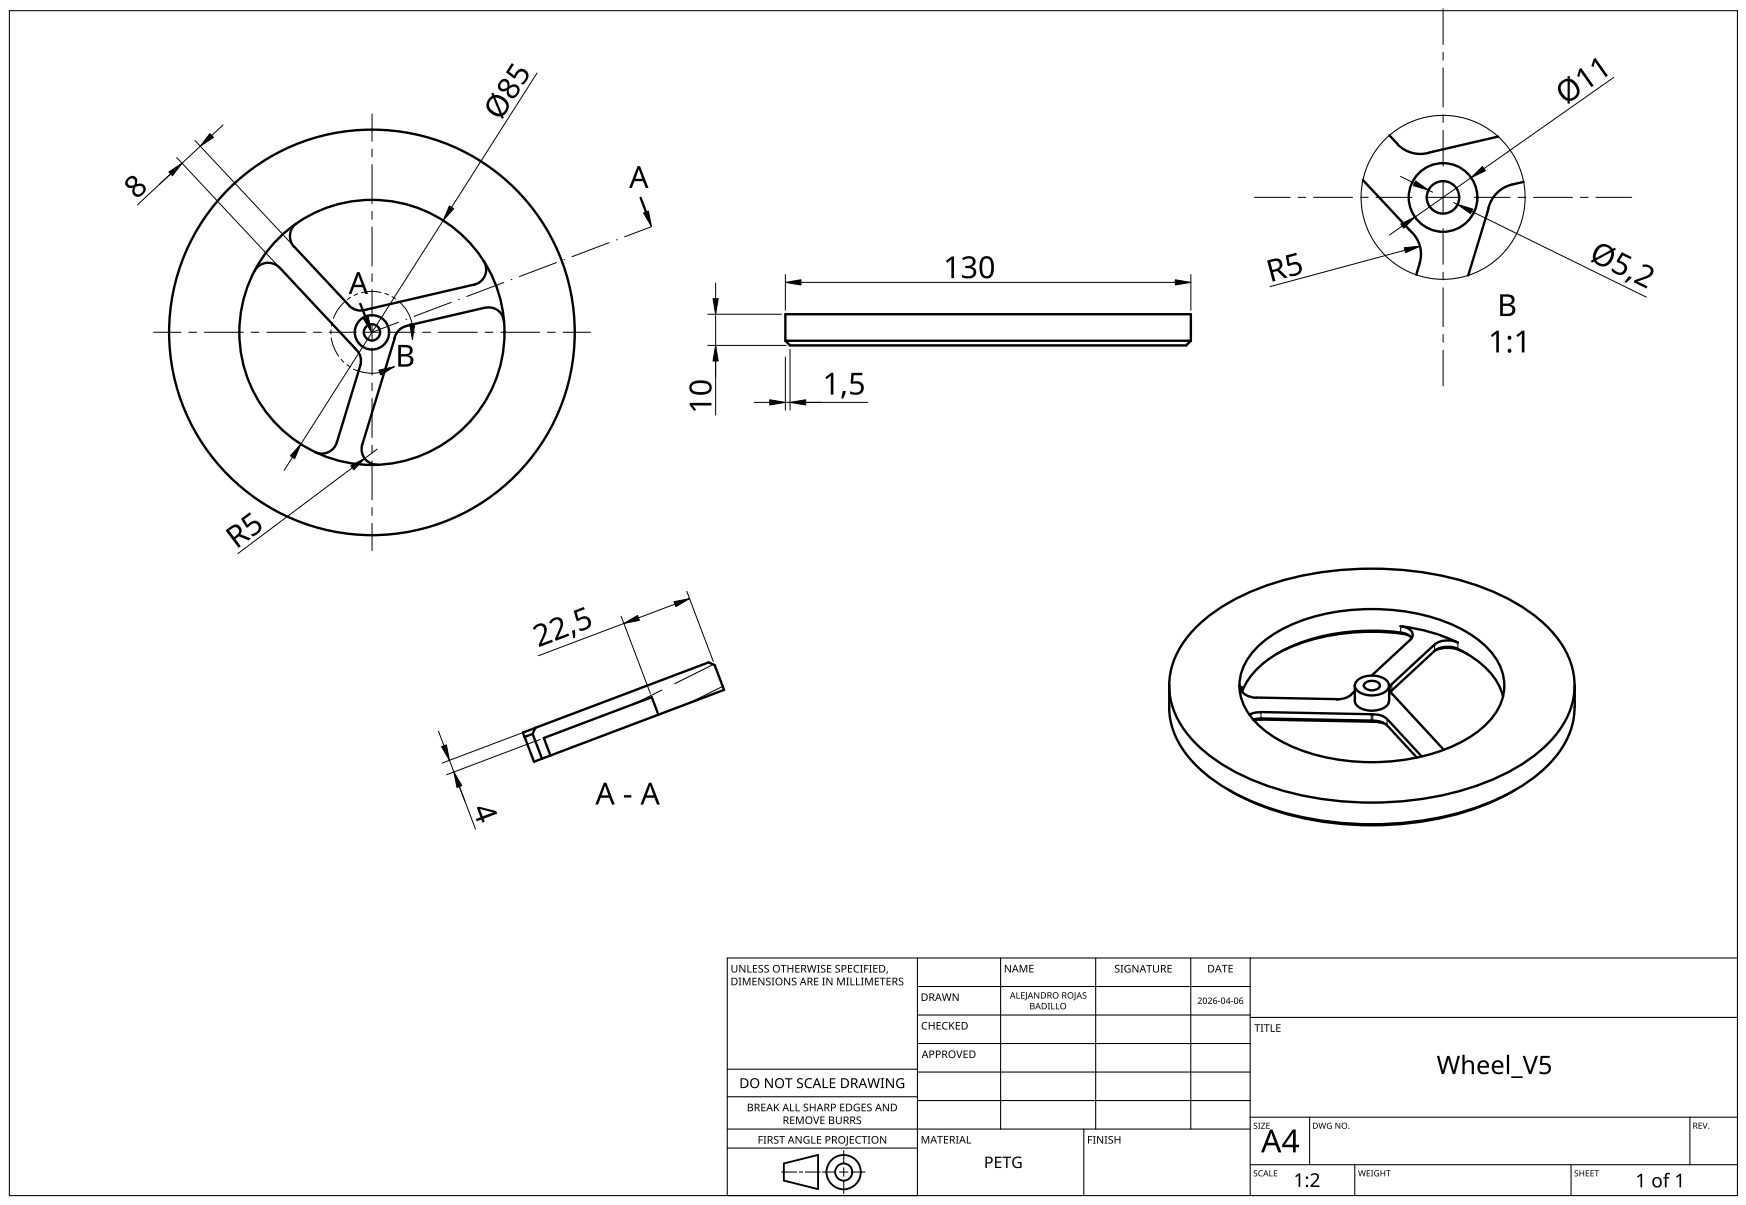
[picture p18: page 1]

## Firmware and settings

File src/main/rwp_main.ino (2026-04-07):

// ================================================================
// Reaction Wheel Pendulum — Controlador LQR Completo
// ESP32 + AS5600 + Encoder 3806 + Driver L298N/TB6612
// ================================================================

#include <Wire.h>

// ================================================================
//  CONFIGURACIÓN
// ================================================================

// ── Ganancias LQR (copia exactamente los valores de MATLAB) ──────
// K = [K_theta, K_thetadot, K_phidot]
const float K_theta    = 15.0;    // ganancia en ángulo
const float K_thetadot = 8.0;     // ganancia en velocidad péndulo
const float K_phidot   = 2.0;     // ganancia en velocidad rueda

// ── Límites del sistema ──────────────────────────────────────────
const float THETA_MAX_DEG   = 25.0;  // ángulo máximo antes de apagar
const float VMAX            = 18.0;  // voltaje máximo del motor [V]
const float PWM_DEADZONE    = 18;    // PWM mínimo donde motor arranca
                                     // (identificar experimentalmente)
const float CONTROL_FREQ_HZ = 500;   // frecuencia del loop [Hz]

// ── Filtro pasa bajas para velocidades ───────────────────────────
const float ALPHA_THETA = 0.20;    // suavizado de θ̇  (0=más suave)
const float ALPHA_PHI   = 0.15;    // suavizado de φ̇  (0=más suave)

// ── Pines ────────────────────────────────────────────────────────
#define ENC_A     18
#define ENC_B     19
#define I2C_SDA   21
#define I2C_SCL   22

// Driver L298N
#define MOTOR_IN1   25    // dirección A
#define MOTOR_IN2   26    // dirección B
#define MOTOR_ENA   27    // PWM enable  (canal LEDC 0)

// O si usas TB6612:
// #define MOTOR_AIN1  25
// #define MOTOR_AIN2  26
// #define MOTOR_PWMA  27
// #define MOTOR_STBY  14   // pull HIGH para habilitar

// ── AS5600 ───────────────────────────────────────────────────────
#define AS5600_ADDR    0x36
#define AS5600_RAW_ANG 0x0C
#define AS5600_STATUS  0x0B

// ── Encoder 3806 ─────────────────────────────────────────────────
#define CPR  2400    // cuentas por revolución (600 PPR × 4)

// ── PWM ESP32 (LEDC) ─────────────────────────────────────────────
#define PWM_CHANNEL   0
#define PWM_FREQ_HZ   20000   // 20kHz — inaudible
#define PWM_BITS      8       // resolución 0-255


// ================================================================
//  VARIABLES GLOBALES
// ================================================================

// Encoder 3806
volatile long enc_count = 0;

// Estados del sistema
float theta        = 0;     // ángulo péndulo [°]
float theta_dot    = 0;     // velocidad péndulo [°/s]
float phi_dot      = 0;     // velocidad rueda [°/s]

// Filtros
float theta_dot_f  = 0;     // θ̇ filtrada
float phi_dot_f    = 0;     // φ̇ filtrada

// Control
float u_control    = 0;     // señal de control [V]
bool  control_activo = false;
bool  sistema_ok     = true;

// Tiempo
unsigned long t_last_us   = 0;
unsigned long t_last_print = 0;
const float   DT_S = 1.0f / CONTROL_FREQ_HZ;
const uint32_t DT_US = (uint32_t)(DT_S * 1e6);

// AS5600
int16_t as_raw_prev = 0;


// ================================================================
//  ISR — Encoder 3806
// ================================================================
void IRAM_ATTR ISR_encoder() {
    bool A = digitalRead(ENC_A);
    bool B = digitalRead(ENC_B);
    if (A == B) enc_count++;
    else        enc_count--;
}


// ================================================================
//  MOTOR
// ================================================================

void motor_init() {
    pinMode(MOTOR_IN1, OUTPUT);
    pinMode(MOTOR_IN2, OUTPUT);
    ledcSetup(PWM_CHANNEL, PWM_FREQ_HZ, PWM_BITS);
    ledcAttachPin(MOTOR_ENA, PWM_CHANNEL);
    motor_stop();
}

void motor_stop() {
    digitalWrite(MOTOR_IN1, LOW);
    digitalWrite(MOTOR_IN2, LOW);
    ledcWrite(PWM_CHANNEL, 0);
}

// Aplica voltaje al motor con compensación de zona muerta
// u en Voltios, rango [-VMAX, +VMAX]
void motor_set_voltage(float u) {

    if (!sistema_ok) {
        motor_stop();
        return;
    }

    // Saturación
    u = constrain(u, -VMAX, VMAX);

    // Zona muerta de control — debajo de umbral el péndulo
    // está tan cerca de cero que no vale la pena actuar
    if (abs(u) < 0.3) {
        motor_stop();
        return;
    }

    // Convertir voltaje a PWM con compensación de zona muerta
    // PWM = zona_muerta + (|u|/Vmax) × (255 - zona_muerta)
    int pwm = (int)(PWM_DEADZONE +
              (abs(u) / VMAX) * (255 - PWM_DEADZONE));
    pwm = constrain(pwm, 0, 255);

    if (u > 0) {
        digitalWrite(MOTOR_IN1, HIGH);
        digitalWrite(MOTOR_IN2, LOW);
    } else {
        digitalWrite(MOTOR_IN1, LOW);
        digitalWrite(MOTOR_IN2, HIGH);
    }

    ledcWrite(PWM_CHANNEL, pwm);
}


// ================================================================
//  AS5600
// ================================================================

int16_t as5600_read_raw() {
    Wire.beginTransmission(AS5600_ADDR);
    Wire.write(AS5600_RAW_ANG);
    Wire.endTransmission(false);
    Wire.requestFrom(AS5600_ADDR, 2);
    if (Wire.available() < 2) return -1;
    uint8_t hi = Wire.read();
    uint8_t lo = Wire.read();
    return ((hi & 0x0F) << 8) | lo;
}

bool as5600_magnet_ok() {
    Wire.beginTransmission(AS5600_ADDR);
    Wire.write(AS5600_STATUS);
    Wire.endTransmission(false);
    Wire.requestFrom(AS5600_ADDR, 1);
    if (!Wire.available()) return false;
    uint8_t s = Wire.read();
    return ((s >> 5) & 1) && !((s >> 4) & 1) && !((s >> 3) & 1);
}

// Velocidad con manejo de wrap-around 0/4095
float as5600_velocity(int16_t raw_now, int16_t raw_prev, float dt) {
    int16_t delta = raw_now - raw_prev;
    if (delta >  2048) delta -= 4096;
    if (delta < -2048) delta += 4096;
    return (delta * 360.0f / 4096.0f) / dt;
}


// ================================================================
//  LECTURA DE ESTADOS
// ================================================================

float get_theta() {
    return ((float)enc_count * 360.0f) / CPR;
}

// ── Seguridad — apaga si el péndulo cae demasiado ────────────────
void check_safety(float angle) {
    if (abs(angle) > THETA_MAX_DEG) {
        sistema_ok = false;
        motor_stop();
        control_activo = false;
    }
}


// ================================================================
//  INICIALIZACIÓN
// ================================================================
void setup() {
    Serial.begin(115200);
    delay(500);

    Serial.println("\n╔══════════════════════════════════════╗");
    Serial.println("║   Reaction Wheel Pendulum — v1.0     ║");
    Serial.println("╚══════════════════════════════════════╝\n");

    // ── 1. Motor (apagado primero por seguridad) ──────────────────
    motor_init();
    Serial.println("[1/5] ✓ Motor inicializado y apagado");

    // ── 2. I2C ────────────────────────────────────────────────────
    Wire.begin(I2C_SDA, I2C_SCL);
    Wire.setClock(400000);
    Serial.println("[2/5] ✓ I2C a 400kHz");

    // ── 3. AS5600 ─────────────────────────────────────────────────
    Serial.print("[3/5] AS5600... ");
    delay(100);
    if (as5600_magnet_ok()) {
        as_raw_prev = as5600_read_raw();
        Serial.println("✓ Imán OK");
    } else {
        Serial.println("⚠ Imán no detectado — verifica distancia");
    }

    // ── 4. Encoder 3806 ───────────────────────────────────────────
    pinMode(ENC_A, INPUT_PULLUP);
    pinMode(ENC_B, INPUT_PULLUP);
    attachInterrupt(digitalPinToInterrupt(ENC_A), ISR_encoder, CHANGE);
    Serial.println("[4/5] ✓ Encoder 3806 con interrupciones");

    // ── 5. Cero del péndulo ───────────────────────────────────────
    Serial.println("[5/5] Posiciona el péndulo en VERTICAL");
    Serial.println("      y envía cualquier carácter por Serial");
    Serial.println("      para establecer el cero...\n");

    while (!Serial.available()) delay(10);
    while (Serial.available()) Serial.read();  // limpiar buffer

    enc_count = 0;
    as_raw_prev = as5600_read_raw();
    theta_dot_f = 0;
    phi_dot_f   = 0;

    Serial.println("✓ Cero establecido\n");

    // Mostrar ganancias activas
    Serial.println("── Ganancias LQR ──────────────────────");
    Serial.print("K_theta    = "); Serial.println(K_theta, 4);
    Serial.print("K_thetadot = "); Serial.println(K_thetadot, 4);
    Serial.print("K_phidot   = "); Serial.println(K_phidot, 4);
    Serial.println("───────────────────────────────────────");
    Serial.println("\nEnvía 'S' para INICIAR control");
    Serial.println("Envía 'P' para PARAR");
    Serial.println("Envía 'R' para RESETEAR cero\n");

    Serial.println("theta\ttheta_d\tphi_d\tu[V]\tOK");

    t_last_us    = micros();
    t_last_print = millis();
}


// ================================================================
//  LOOP PRINCIPAL
// ================================================================
void loop() {

    // ── Comandos seriales ─────────────────────────────────────────
    if (Serial.available()) {
        char cmd = toupper(Serial.read());

        if (cmd == 'S') {
            sistema_ok     = true;
            control_activo = true;
            enc_count      = 0;
            phi_dot_f      = 0;
            theta_dot_f    = 0;
            Serial.println("▶ Control ACTIVO");

        } else if (cmd == 'P') {
            control_activo = false;
            motor_stop();
            Serial.println("■ Control PAUSADO");

        } else if (cmd == 'R') {
            enc_count   = 0;
            as_raw_prev = as5600_read_raw();
            sistema_ok  = true;
            Serial.println("↺ Cero restablecido");
        }
    }

    // ── Loop de control ───────────────────────────────────────────
    unsigned long t_now = micros();
    if (t_now - t_last_us < DT_US) return;  // esperar el período

    float dt = (t_now - t_last_us) * 1e-6f;
    t_last_us = t_now;

    // Limitar dt por si hubo retraso (protección)
    dt = constrain(dt, 0.0005f, 0.005f);

    // ── Leer estados ──────────────────────────────────────────────
    static float theta_prev = 0;

    theta = get_theta();

    // Velocidad del péndulo — derivada + filtro
    float theta_dot_raw = (theta - theta_prev) / dt;
    theta_dot_f = ALPHA_THETA * theta_dot_raw +
                  (1 - ALPHA_THETA) * theta_dot_f;
    theta_prev = theta;

    // Velocidad de la rueda — AS5600 + filtro
    int16_t raw_now = as5600_read_raw();
    if (raw_now >= 0) {
        float phi_dot_raw = as5600_velocity(raw_now, as_raw_prev, dt);
        phi_dot_f   = ALPHA_PHI * phi_dot_raw +
                      (1 - ALPHA_PHI) * phi_dot_f;
        as_raw_prev = raw_now;
    }

    // ── Verificar seguridad ───────────────────────────────────────
    check_safety(theta);

    if (!sistema_ok) {
        motor_stop();
        if (millis() - t_last_print > 500) {
            t_last_print = millis();
            Serial.println("⛔ SISTEMA CAÍDO — envía 'R' para resetear");
        }
        return;
    }

    // ── Controlador LQR ──────────────────────────────────────────
    if (control_activo) {

        // Convertir a radianes para que coincida con las
        // ganancias calculadas en MATLAB (que usa radianes)
        float theta_rad    = theta     * DEG_TO_RAD;
        float thetadot_rad = theta_dot_f * DEG_TO_RAD;
        float phidot_rad   = phi_dot_f   * DEG_TO_RAD;

        // u = -K·x
        u_control = -(K_theta    * theta_rad    +
                      K_thetadot * thetadot_rad +
                      K_phidot   * phidot_rad);

        motor_set_voltage(u_control);

    } else {
        motor_stop();
        u_control = 0;
    }

    // ── Telemetría serial a 10 Hz ─────────────────────────────────
    if (millis() - t_last_print >= 100) {
        t_last_print = millis();

        Serial.print(theta, 3);       Serial.print("\t");
        Serial.print(theta_dot_f, 2); Serial.print("\t");
        Serial.print(phi_dot_f, 2);   Serial.print("\t");
        Serial.print(u_control, 3);   Serial.print("\t");
        Serial.println(control_activo ? "ON" : "OFF");
    }
}

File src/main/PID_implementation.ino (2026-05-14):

// Implementación de sistema de control por PID anidado en la rueda de reacción con ESP32, Motor JGA-25, driver L293D
#include <Arduino.h>
#include <PID_v1.h>
#include <ESP32Encoder.h>

// ── Pines ─────────────────────────────────────────────────────────
const int Encoder1A = 18;
const int Encoder1B = 19;
const int Encoder2A = 22;
const int Encoder2B = 23;
const int dirA      = 15;
const int dirB      = 4;
const int enable    = 5;

volatile long encoderCount = 0; // Contador de pulsos
unsigned long lastMicros = 0;   // Para debounce
const unsigned long debounceTime = 500; 

// ── Constantes ────────────────────────────────────────────────────
const float CPR1     = 1200.0f;   // 600 PPR para HalfQuad
const float CPR2     = 980.0f;    // 490 PPR 
const int   DT_MS    = 10;        // período del loop 
const float DT_S     = DT_MS / 1000.0f;
const float THETA_MAX = 100.0f;
const int   PWM_DEAD  = 20;       // zona muerta 

// ── Variables de estado ───────────────────────────────────────────
float theta      = 0, theta_prev = 0, 
float phi        = 0, phi_prev   = 0, phi_dot   = 0;

// ── PID 
double Setpoint_ext = 0,  Input_ext = 0,  Output_ext = 0;
double Setpoint_int = 0,  Input_int = 0,  Output_int = 0;

// Ganancias — empezar en 0 y subir durante sintonización
double Kp_ext = 160.0, Ki_ext = 0, Kd_ext = 2.0;
double Kp_int = 1.0, Ki_int = 0.4, Kd_int = 0.1;

PID PID_ext(&Input_ext, &Output_ext, &Setpoint_ext,
            Kp_ext, Ki_ext, Kd_ext, DIRECT);

PID PID_int(&Input_int, &Output_int, &Setpoint_int,
            Kp_int, Ki_int, Kd_int, DIRECT);

ESP32Encoder encoderA;
ESP32Encoder encoderB;

// ── Timing ────────────────────────────────────────────────────────
unsigned long t_last_control = 0;
unsigned long t_last_serial  = 0;


// ── Motor ─────────────────────────────────────────────────────────
void motor_apply(float u) {
  //int pwm = (int)constrain(fabsf(u), 0, 255);  // ← valor absoluto
  int pwm = (int)u;
 
  if (pwm > 35) {
    digitalWrite(dirA, HIGH);
    digitalWrite(dirB, LOW);
    analogWrite(enable, pwm);
  } else if (pwm < -35) {
    digitalWrite(dirA, LOW);
    digitalWrite(dirB, HIGH);
    analogWrite(enable, -pwm);
  } else {
    analogWrite(enable, 0);
  }
    
}



//  SETUP
void setup() {
  Serial.begin(115200);
  delay(500);

  // Motor apagado primero
  pinMode(dirA,   OUTPUT);
  pinMode(dirB,   OUTPUT);
  pinMode(enable, OUTPUT);
  digitalWrite(dirA, LOW);
  digitalWrite(dirB, LOW);
  analogWrite(enable, 0);

  // Encoders

  ESP32Encoder :: useInternalWeakPullResistors = puType :: up;
  encoderA.attachHalfQuad(18, 19);
  encoderB.attachHalfQuad(22, 23);

  encoderA.clearCount();
  encoderB.clearCount();
  
  // PID — período de cómputo igual al loop
  PID_ext.SetMode(AUTOMATIC);
  PID_int.SetMode(AUTOMATIC);
  PID_ext.SetSampleTime(DT_MS);    // sincronizar con tu loop
  PID_int.SetSampleTime(DT_MS);

  // Límites de salida
  PID_ext.SetOutputLimits(-800, 800);  // referencia de vel. rueda [°/s]
  PID_int.SetOutputLimits(-255, 255);  // PWM al motor

  // Setpoint externo siempre en 0 (queremos θ=0)
  Setpoint_ext = 0;
  Setpoint_int = 0;

  Serial.println("Posiciona péndulo en vertical y envía cualquier tecla");
  while (!Serial.available()) delay(10);
  Serial.read();
  Serial.println("✓ Cero establecido. Esperando...");
  Serial.println("Comandos: S=iniciar  P=pausar  R=reset");

  t_last_control = millis();
  t_last_serial  = millis();
  
}


//  LOOP
bool activo = false;

void loop() {

  // ── Comandos seriales ─────────────────────────────────────
  if (Serial.available()) {
    String lectura = Serial.readStringUntil('\n');
    lectura.trim();

    int index = lectura.indexOf(',');
    String cmd = lectura.substring(0, index);
    double valor = lectura.substring(index+1).toDouble();
    
    if (cmd == "S") {
      activo = false; // Pausar un momento
      
      // 1. Cero en encoders
      encoderA.setCount(0);
      encoderB.setCount(0);

      theta = 0; phi = 0;
      theta_prev = 0; phi_prev = 0;
      theta_dot = 0; phi_dot = 0;
      Input_ext = 0; Input_int = 0;

      // 3. Reiniciar la memoria integral de los PIDs (Bumpless Transfer)
      PID_ext.SetMode(MANUAL); 
      PID_int.SetMode(MANUAL);
      Output_ext = 0; 
      Output_int = 0;
      PID_ext.SetMode(AUTOMATIC); 
      PID_int.SetMode(AUTOMATIC);

      activo = true;  // Arrancar limpio
      Serial.println("▶ Activo (Limpio)");
    } else if (cmd == "P"){
      activo = false; analogWrite(enable, 0); Serial.println("■ Pausado");
    } else if (cmd == "R"){
      // 1. Cero en encoders
      encoderA.setCount(0);
      encoderB.setCount(0);
      
      theta = 0; phi = 0;
      theta_prev = 0; phi_prev = 0;
      theta_dot = 0; phi_dot = 0;
      Input_ext = 0; Input_int = 0;

      // 3. Reiniciar la memoria integral de los PIDs (Bumpless Transfer)
      PID_ext.SetMode(MANUAL); 
      PID_int.SetMode(MANUAL);
      Output_ext = 0; 
      Output_int = 0;
      PID_ext.SetMode(AUTOMATIC); 
      PID_int.SetMode(AUTOMATIC);
      Serial.println("↺ Reset");
    } else if (cmd == "KP"){
      Kp_ext = valor;
      PID_ext.SetTunings(Kp_ext, Ki_ext, Kd_ext);
    } else if (cmd == "KD"){
      Kd_ext = valor;
      PID_ext.SetTunings(Kp_ext, Ki_ext, Kd_ext);
    } else if (cmd == "KI"){
      Ki_ext = valor;
      PID_ext.SetTunings(Kp_ext, Ki_ext, Kd_ext);
    }
    
  }

  // ── Loop de control a 100 Hz ──────────────────────────────
  if (millis() - t_last_control < DT_MS) return;
  t_last_control = millis();

  // Leer encoders
  long c1 = encoderA.getCount();
  long c2 = encoderB.getCount();

  theta = (c1 * 360.0f) / CPR1;
  phi   = (c2 * 360.0f) / CPR2;

  // Velocidades con filtro pasa bajas
  //theta_dot =  0.2f * ((theta - theta_prev) / DT_S) + 0.8f * theta_dot;
  //theta_dot = (theta - theta_prev) / DT_S;
  phi_dot   =  0.2f * ((phi   - phi_prev)   / DT_S) + 0.8f * phi_dot;
  //phi_dot = (phi   - phi_prev)   / DT_S;
  //theta_prev = theta;
  phi_prev   = phi;

  if (!activo) return;

  if (fabsf(theta) > 25 ){
    activo = false; analogWrite(enable, 0); Serial.println("■ Pausado");
  }

  // Actualizar entradas PID 
  Input_ext = theta;
  Input_int = phi_dot;

  // PID externo: θ → referencia de velocidad de rueda
  PID_ext.Compute();
  Setpoint_int = -Output_ext;   // ← cascada: salida ext es setpoint int

  // PID interno: φ̇ → PWM del motor
  PID_int.Compute();

  // Aplicar al motor
  motor_apply((float)Output_int);

  // ── Serial a 10 Hz ────────────────────────────────────────
  if (millis() - t_last_serial >= 100) {
    t_last_serial = millis();

    Serial.print(Kp_ext); Serial.print("\t"); Serial.print("\t");
    Serial.print(Ki_ext); Serial.print("\t"); Serial.print("\t");
    Serial.print(Kd_ext); Serial.print("\t"); Serial.print("\t");
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

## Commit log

2026-04-06 Add physical parameters for Reaction Wheel Pendulum
    This file contains physical parameters for the Reaction Wheel Inverted Pendulum system, including mass, inertia, and motor specifications.
2026-04-06 Initialize ESP32 DAQ for Reaction Wheel Pendulum
2026-04-06 Add real-time monitoring for Reaction Wheel Pendulum
2026-04-06 Add sensor_test.ino for Reaction Wheel Pendulum
    Initial implementation of sensor reading for Reaction Wheel Pendulum using ESP32, AS5600, and Encoder 3806.
2026-04-07 Add Reaction Wheel Pendulum control code
2026-04-07 Implement sensor test for Reaction Wheel Pendulum
    Add sensor test for Reaction Wheel Pendulum using ESP32 and AS5600.
2026-04-07 Archivos STL añadidos
    [Arm_V10_STL.stl, Support_V5.stl, Tower_V7_STL.stl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]
2026-04-16 Revise README for repository structure and file references
    Updated repository structure and corrected references to CAD and documentation files.
2026-05-14 Add PID control implementation for reaction wheel
    Implement PID control system for reaction wheel using ESP32.
